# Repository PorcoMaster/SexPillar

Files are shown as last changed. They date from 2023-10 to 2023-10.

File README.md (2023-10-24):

# SexPillar
SexPillar is an advanced, fully parametric endstop, drawing inspiration from Unklicky, Sexbolt, and Unklicky_z. Crafted with meticulous attention to detail in Fusion, the design file encompasses a wide range of possibilities and is annotated with comments to ensure ease of use. Tailored specifically for printers with a metallic plate, it incorporates a robust magnet at its base. This magnetic feature not only ensures stability but also facilitates precise adjustments along the X and Y axes. Moreover, its adaptability shines, as it can accommodate any magnet, screw, wire, and heat insert. Primarily, SexPillar is optimized for use with an auto_Z macro, streamlining the calculation of nozzle offsets and babysteps.
# Disclaimer

This bill of materials is based on what I had readily available. While the associated .f3d file is fully parametric, I do not recommend purchasing the items listed verbatim. Instead, evaluate what you have on hand and adjust accordingly. Larger tower(Tube Height) and window dimensions (HWC) may offer greater ease during assembly. In essence, with the right specifications, you could construct the 'sexpillar' using just one screw, one sexbolt, two magnets, and two wires. I incorporated numerous heat inserts in my design due to my personal preference and because I had an abundance of them.

PS: if you do change Tube Height, remember to also adjust PinHoleHeight

In the Fusion file, all elements are parametric. However, the hardware is primarily for initial visualization. When adjusting parameters, the hardware may not align with all parts. For a clearer view when modifying parameters, it's recommended to hide all hardware.

# Update 10/20/2023

Added a bracket version for using with T-slots and any kind of screws to attach it, also totally Parametric 

Information and pictures of added parameters in the end

# Update 10/24/2023

I was unable to find a program or program myself to babystep a bedslinger with sexpillar :/..., but i tested it and it works wonders as an endstop, so i am sure a lot of people will find use on it 

right now i just modified my printer.cfg and i am using as a button, in my case scenario that i am always tweaking my printers i was missing the option to move my printer without having to Home or g28. 

so i just added a SET_KINEMATIC_POSITION, you could use as anything i think even as an emergecy button might work. 

this is my code in case you want to do something, please be carefull SET_KINEMATIC_POSITION is dangerous if you don't know what you are doing. 
also SET_KINEMATIC_POSITION just works if force_move is set to true.
```
[gcode_button my_gcode_button]
pin: ^secondary:PA6
press_gcode:
    M118 Please home as soon as possible
    M117 Please home as soon as possible
    SET_KINEMATIC_POSITION X=150 Y=150 Z=0
```

# General Bill of Materials (BOM)

List of Hardware

- 20x5mm Magnet - 1 Units

- 6x2mm Magnet - 2 Units

- Heatinsert M3x4mm - 1 Unit

- HeatInsert M3 5mm - 1 Unit

- M3 Screw 16mm - 1 Unit

- M3 Screw 6mm - 1 Unit

- M4 SexBolt - 1 Unit / bigger than 8mm without lid, bigger than 12 mm with lid

Optional with putting LID, LID is completely Cosmestic

- M2 Screw 6mm - 2 Units

- M2 Heatinsert 3mm - 2 Units

[Heatinsert](https://www.amazon.com/Swpeet-Embedment-Hydraulic-Injection-Assortment/dp/B08YYGRCBG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) i used was from this kit, if you are using a different one please go into file and change sizes

# Parameters

- **BMD (Big Magnet Diameter):** 
  - 20 mm
  - Refers to the diameter of the larger magnet used in the design.
  
- **BMH (Big Magnet Height):** 
  - 5 mm
  - Specifies the height of the larger magnet.
  
- **SMD (Small Magnet Diameter):** 
  - 6 mm
  - Diameter of a smaller magnet
  
- **SMH (Small Magnet height):** 
  - 4 mm
  - The height of the smaller magnet.
  
- **HD (Heat Insert Diameter):** 
  - 4.3 mm
  - Diameter of the Bigger heat insert
  
- **HH (Heat Insert Height):** 
  - 8 mm
  - The vertical size of the Bigger heat insert.
  
- **TPH (Tolerance of Printer in holes):** 
  - 0.6 mm
  - The Printer typical Tolerance
  
- **NozzleSize:** 
  - 0.4 mm
  - The diameter of the 3D printer nozzle
  
- **Wall:** 
  - 4.8 mm (12 * NozzleSize)
  - Thickness of the wall, calculated based on the nozzle size.
  
- **DMG (Distance from magnet to ground):** 
  - 0.6 mm
  - This gap ensures the magnet doesn't touch the base or ground. so it doens't scratch, too big and you will not have a good grip
    too small and you will scratch your table.
  
- **LayerHeight:** 
  - 0.2 mm
  - Each 3D print layer's height, determining the print's resolution.
  
- **WSM (Wall separating magnet):** 
  - 0.6 mm (3 * LayerHeight)
  - The thickness of the wall that separates individual magnets. too small, weak wall, too big you have a problem with magnetic not having enough force to push.
  
- **DP (Diameter Pin):** 
  - 8.4 mm
  - Refers to the diameter of a pin used in the assembly.
  
- **PHe (Pin Height):** 
  - 25 mm
  - The vertical dimension or height of the pin.
  
- **FP1 (Flatten Pin adjustment):** 
  - 1 mm
  - Amount to reduce the pin's side.
  
- **FP2 (Opposite side adjustment):** 
  - 1 mm
  - A similar adjustment as FP1 but applied to the opposite side.
  
- **SCD (Screw Contact Diameter):** 
  - 3 mm
  - Diameter where the screw makes contact
  - 
- **TSW (Tolerance Screw Window):** 
  - 0.6 mm
  - The allowable deviation in the screw placement window to ensure a proper fit.
  
- **HWC (Height Window contact with added half circle):** 
  - 3.6 mm (SCD + 0.6 mm)
  - Refers to the height of the contact window that includes an extra half-circle design.
  
- **TSexyBolt (Thread Sexy Bolt):** 
  - 5.5 mm
  - The length of the threaded section of "sexy bolt". You need to edit this directly on the design timeline.
  
- **HTsexyBolt (Height Thread SexyBolt):** 
  - 4 mm
  - Specifies the height of the threaded of the "sexy bolt".
  
- **TubeHeight:** 
  - 35 mm (PHe + 10 mm)
  - The vertical dimension of the Tube.
  
- **SHD (Small Heat Insert Diameter):** 
  - 2.7 mm
  - Diameter of a smaller variant of the heat insert.
  
- **SHH (Small Heat Insert Height):** 
  - 3.5 mm
  - Vertical size of the smaller heat insert.
  
- **SSD (Small Screw Diameter):** 
  - 2 mm
  - Diameter of the smaller screws used in the design.
  
- **PINholeHeight:** 
  - 16.4 mm
  - Represents the depth of a hole specifically made to accommodate a pin.

- [Teste](https://github.com/PorcoMaster/SexPillar/blob/main/Images%20And%20Videos/Video%20Teste.mp4) 

- [Moving](https://github.com/PorcoMaster/SexPillar/blob/main/Images%20And%20Videos/Video%20moving.mp4)

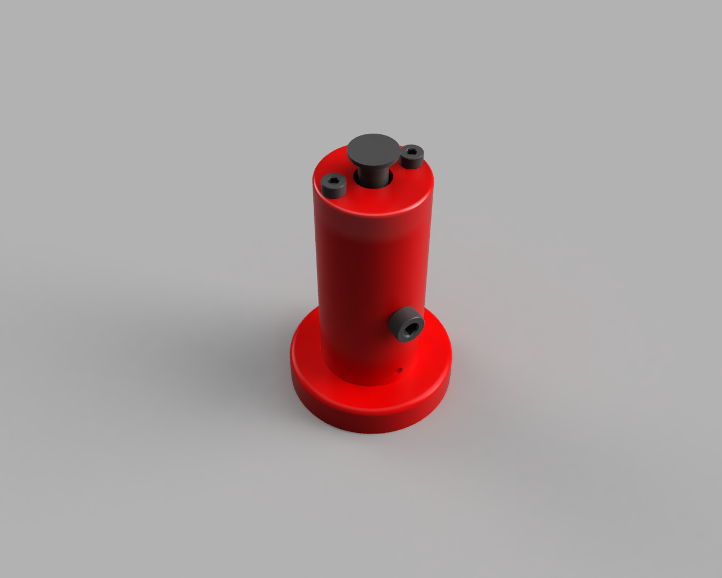
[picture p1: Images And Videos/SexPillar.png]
SexPillar

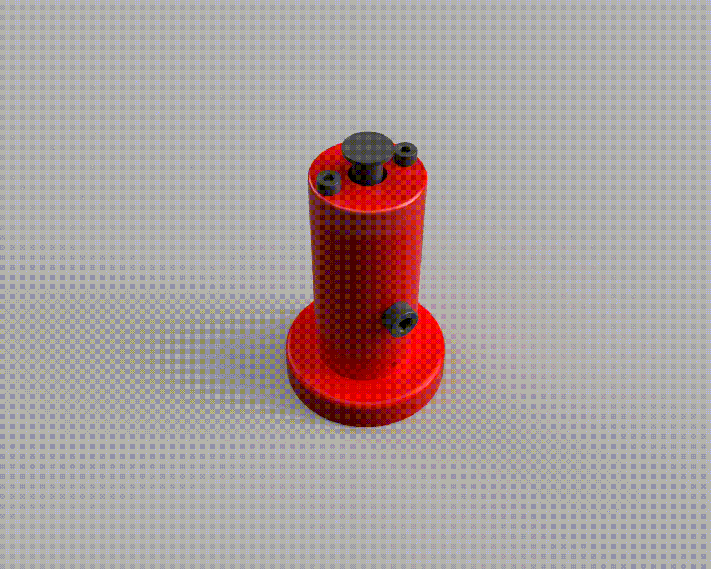
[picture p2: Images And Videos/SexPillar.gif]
Appresentation


Tutorial
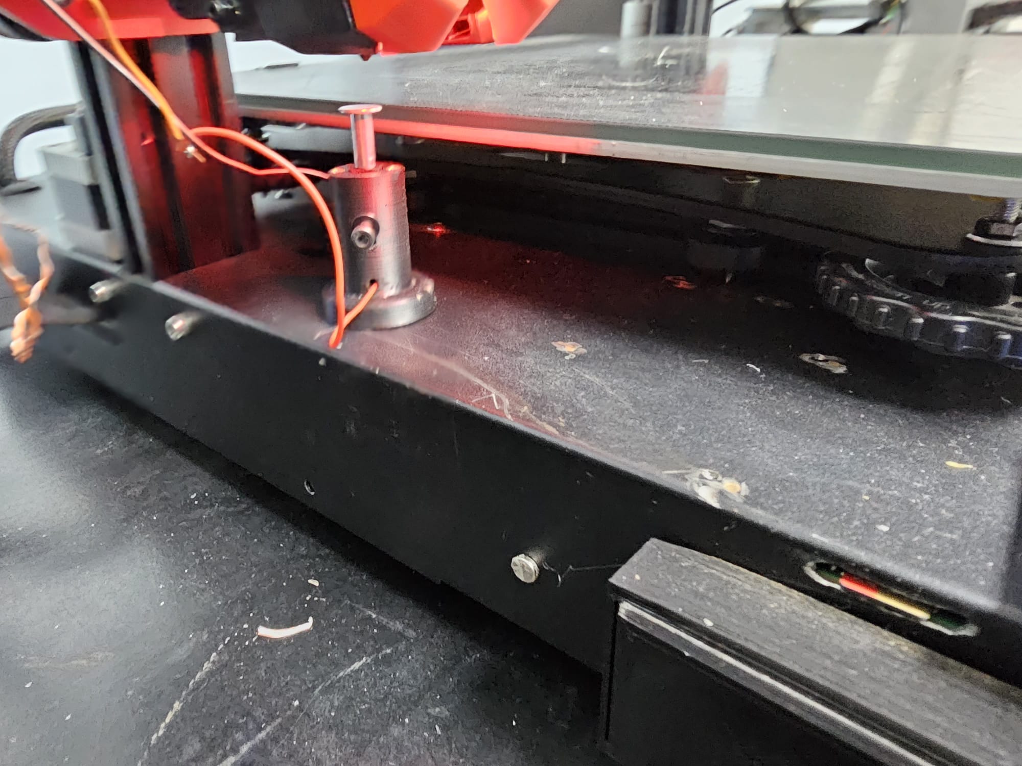
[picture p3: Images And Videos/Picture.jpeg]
Real


# Parameters MOD Bracket 

- DFM = Distance from middle
- DFG = Distance from Ground
- LB = Lenght of Bracket
- HB = Height of Bracket
- AB = Angle of Bracket
- DFS = Distance of Brackets
- SBS = Screw Bracket Size

Keep in mind that you just need to make visible the bracket that you want then you go to component and save as mesh, this parameters change both options. there is a horizontal and vertical brackets, and they can change angles

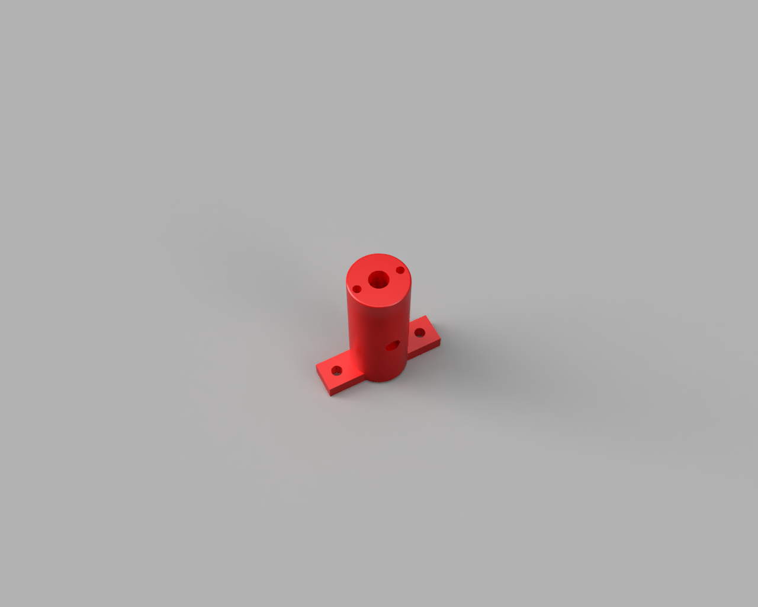
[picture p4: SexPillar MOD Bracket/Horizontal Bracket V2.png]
SexPillar

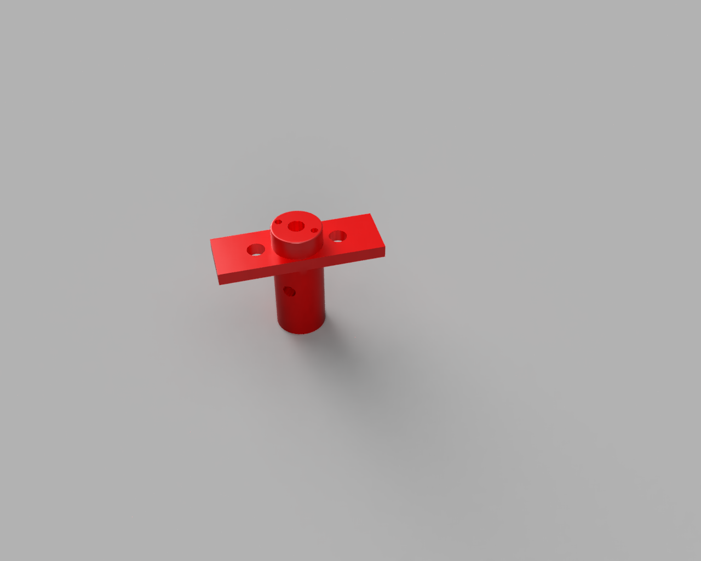
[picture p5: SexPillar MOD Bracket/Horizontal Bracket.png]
SexPillar

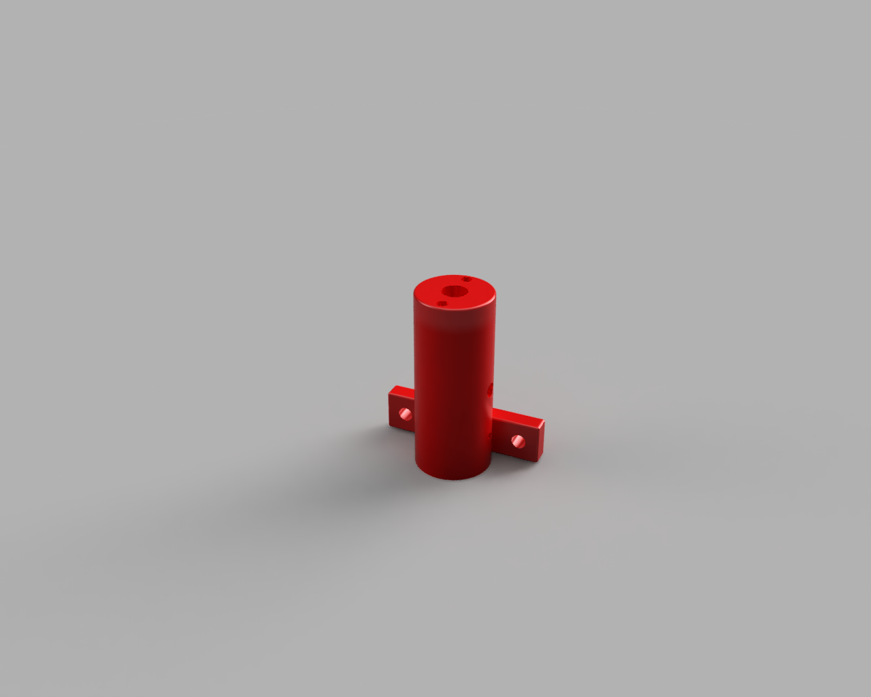
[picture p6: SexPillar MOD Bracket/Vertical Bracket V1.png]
SexPillar

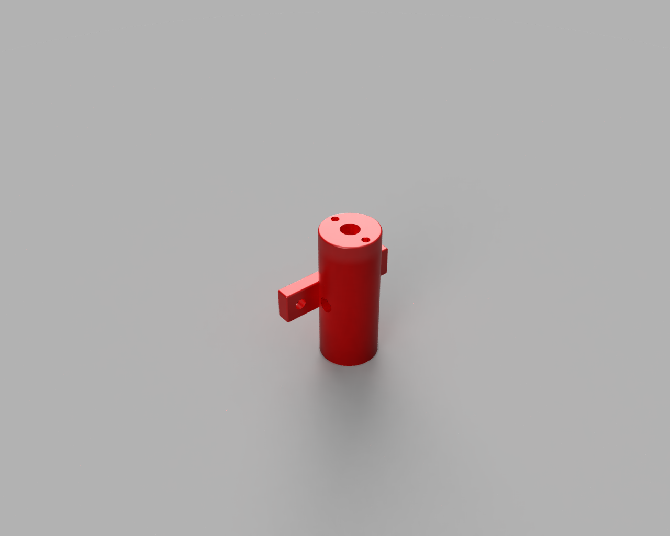
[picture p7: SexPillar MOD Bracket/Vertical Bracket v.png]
SexPillar

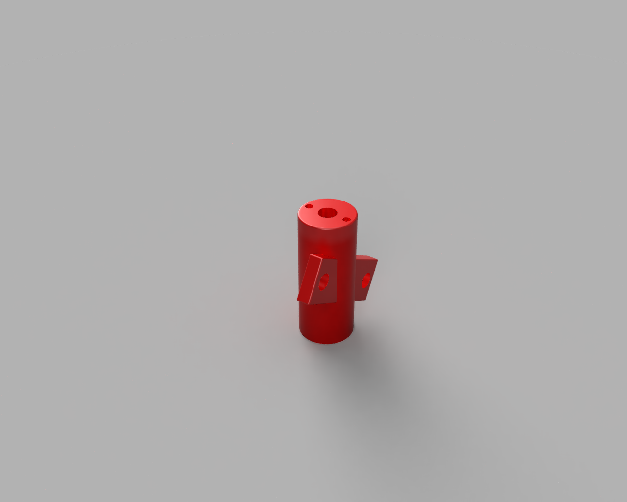
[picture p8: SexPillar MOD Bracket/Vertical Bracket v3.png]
SexPillar


Shield: [][cc-by-nc-sa]

This work is licensed under a
[Creative Commons Attribution-NonCommercial-ShareAlike 4.0 International License][cc-by-nc-sa].

[][cc-by-nc-sa]

[cc-by-nc-sa]: http://creativecommons.org/licenses/by-nc-sa/4.0/
[cc-by-nc-sa-image]: https://licensebuttons.net/l/by-nc-sa/4.0/88x31.png
[cc-by-nc-sa-shield]: https://img.shields.io/badge/License-CC%20BY--NC--SA%204.0-lightgrey.svg

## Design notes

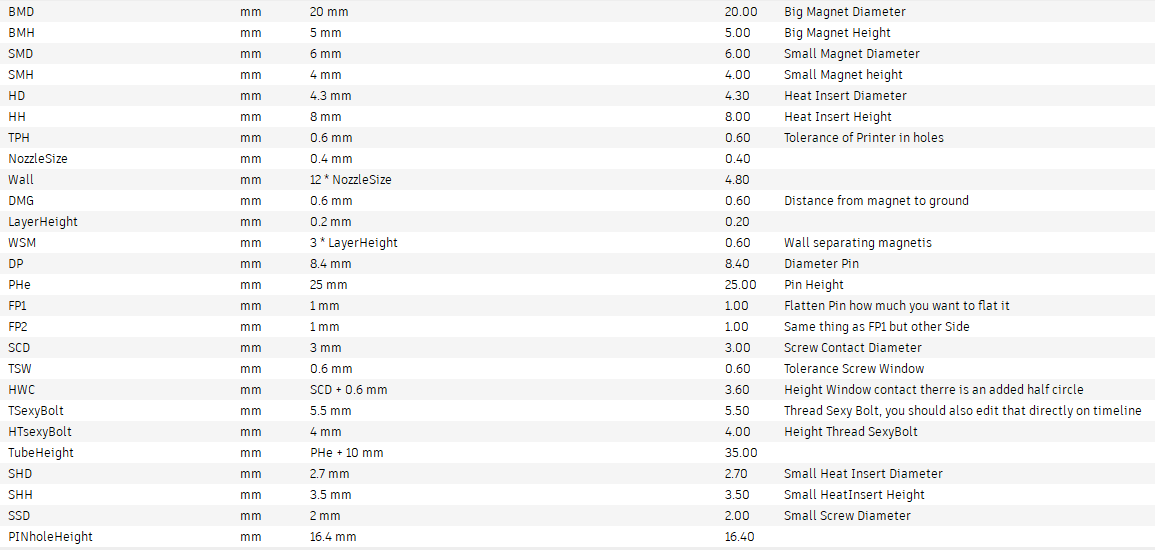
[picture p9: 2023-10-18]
Images And Videos/Parameters.png

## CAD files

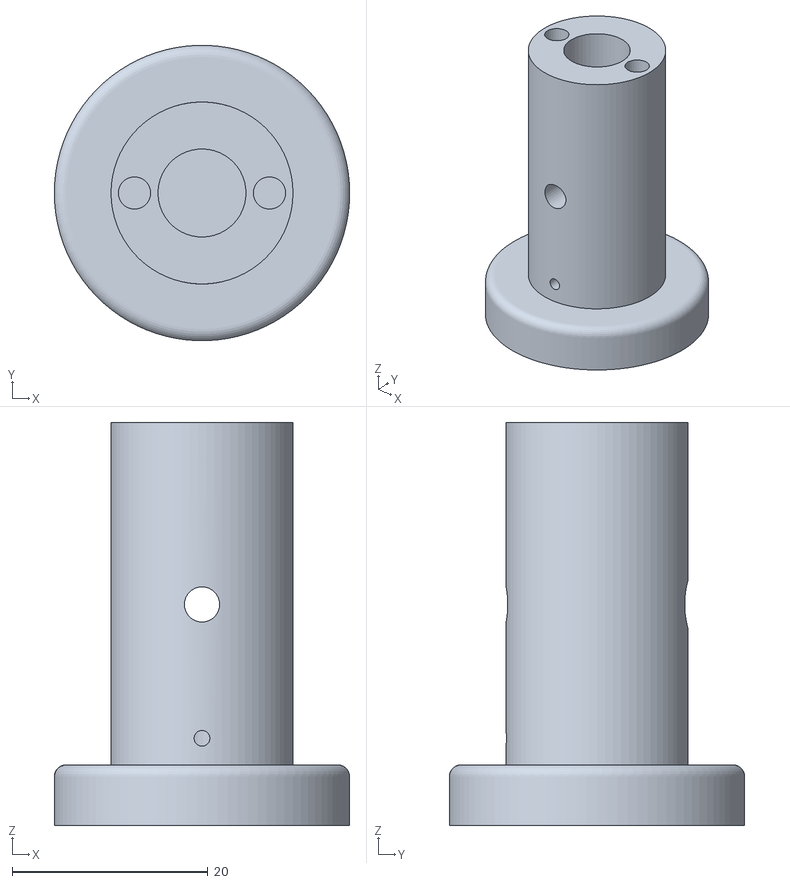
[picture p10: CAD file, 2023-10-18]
STL/SexPillar Mainbody.stl
30.2 x 30.2 x 41.2

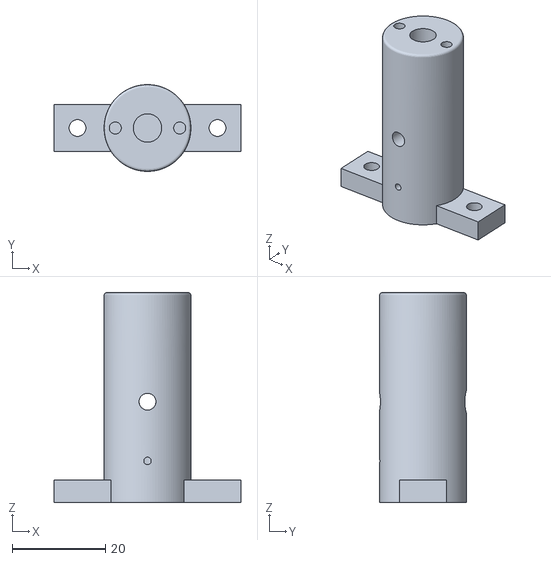
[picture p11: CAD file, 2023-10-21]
SexPillar MOD Bracket/SexPillar Vertical Bracket v4.stl
40.0 x 18.6 x 45.0

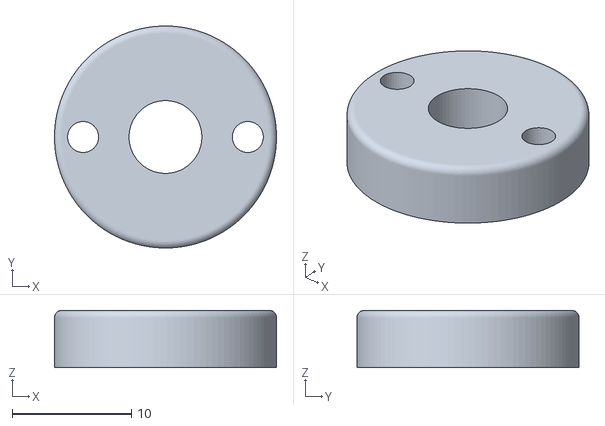
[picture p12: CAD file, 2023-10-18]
STL/SexPillar LID Optional.stl
18.6 x 18.6 x 4.80

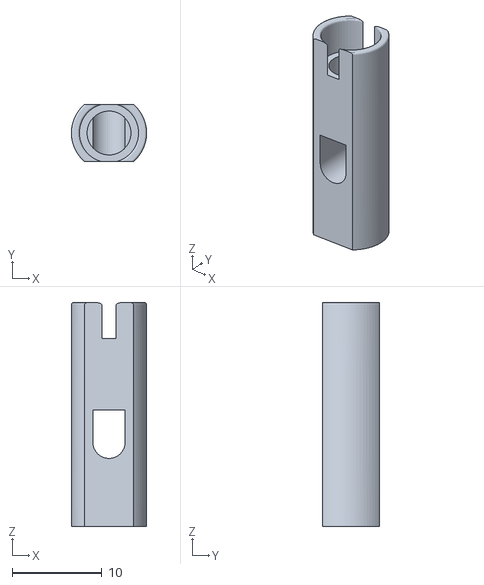
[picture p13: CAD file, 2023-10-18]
STL/SexPillar Pin.stl
8.40 x 6.40 x 25.0

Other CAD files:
SexPillar MOD Bracket/SexPillar Horizontal Bracket v4.stl
F3D/SexPillar.f3d
SexPillar MOD Bracket/SexPillar Bracket v6.f3d

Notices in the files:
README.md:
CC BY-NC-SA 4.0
